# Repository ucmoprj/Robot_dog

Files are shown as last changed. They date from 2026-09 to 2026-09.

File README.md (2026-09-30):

# MG90S Dog R1

A mechanical design for review that rebuilds the **4 legs × 3 joints** layout of Rhoban's `dog_mujoco` and `dog_urdf` around MG90S servos. The joint names and kinematic structure of both originals were checked, and new geometry, masses, inertias and joint limits were made for the MG90S. It is not a simple scaled-down copy of the original CAD.

Generated output is in `out/mg90s_dog`. This design is separate from the `leg_*.step` files and `sim` model of the earlier ESP32 quadruped.

## Design constraints

- 12 × MG90S: 4 body-side roll, 4 hip pitch, 4 knee pitch.
- Body plate 116 × 66 mm, shoulder vertical offset 37 mm, lateral offset 16 mm.
- Upper leg 44 mm between axes, 38 mm from the lower-leg axis to the foot center, foot radius 5 mm.
- Default knee angle 42°. The hip angle is computed from the two link lengths so the foot sits under the hip.
- Roll is limited to 18° outward and 6° inward. Tilting too far inward makes the leg hit the opposite knee servo, so left and right legs get limits of opposite sign.
- Estimated mass follows the generated `design_summary.json` and `bom.csv`: a conditional estimate of about 0.31 kg.
- Includes battery 30 g, PCA9685 12 g, controller board 10 g, IMU 2 g, wiring/regulator 10 g, fasteners 10 g. Extra payload 0 g.
- The effective print density of 900 kg/m³ is an assumption. Replace it with the slicer's filament usage and the measured weight.

From the manufacturer's MG90S spec: mass 13.4 g, overall size 22.8 × 12.2 × 28.5 mm, stall torque about 0.1765 N·m at 4.8 V, 60°/0.10 s. **The 0.06 N·m design limit is a conservative assumption, not a continuous torque guaranteed by the manufacturer.** Mounting ears, output shaft position and horn hole sizes are adjustable values that need checking against the real part.

Source: https://towerpro.com.tw/product/mg90s-3/

## Opening in Onshape

1. To check the shape, import `onshape/mg90s_dog_assembly.step`. It is saved in the standing pose.
2. To build a movable Assembly, **`onshape/mg90s_dog_zero.step`** is easier. The body origin is at (0,0,0) and every joint is at its geometric reference angle of 0°. This pose is the assembly reference, not a walking pose.
3. The STEP hierarchy has 13 rigid groups such as `body`, `fl_shoulder`, `fl_thigh`, `fl_shank`. Fix the parts of each group so they move together.
4. Create 12 Revolute Mates following the origins and axes in `onshape/onshape_mates.csv`. Align each Mate connector's Z axis with the rotation axis in the table. Name them `dof_fl_1` through `dof_br_3`.
5. Apply the rotation limits and standing angles from the CSV. `*_1` is roll, `*_2` hip pitch, `*_3` knee pitch.
6. The IMU frame is at (0,0,26) mm in the body frame, X forward, Y left, Z up. It can be added as `frame_imu`.

STEP carries shape, names and placement. **It does not create Onshape Mates or the original sketch/feature history.** Depending on how the hierarchy imports, group the parts of each rigid body with Group or Fastened Mates. The CAD model was generated locally and did not modify the user's Onshape documents directly.

If you build mates directly on the standing STEP, the current pose may become 0°. The CSV's absolute angles would then be wrong, so the zero STEP is recommended. When exporting again with `onshape-to-robot`, compare the joint axes, zeros and masses with the current MJCF. Do not let Onshape estimate the MG90S internal mass from a generic material density; apply the rigid-body masses and inertias from `design_summary.json` separately.

Source: https://onshape-to-robot.readthedocs.io/en/latest/design.html

## Printing and assembly

`onshape/parts` holds a STEP per printed part and `onshape/print_stl` holds STLs in mm. Part files keep their rigid-body coordinates, so place a flat face on the bed in the slicer. Some parts are mirrored for left/right and front/back mounting; keep the file names.

First check the servo case clearance, ear hole spacing and pilot holes with `servo_fit_coupon.step` or the STL of the same name. Use the horns that ship with the MG90S; the round horn in the model is a stand-in for mass and space. Do not assume a printed spline will mate with the servo shaft. If the real horn shape and the 6 mm-radius screw holes differ, change `horn_screw_radius` and related values.

Screw the servo ears to the frame and the horn to the rotating bracket. There is an access hole for the horn's center screw. After checking plate/frame and screw fit, assemble one leg and check its motion. The current design relies on the MG90S's own output shaft support; it is not a double-supported design with external bearings. Drop/impact durability and horn/pilot-hole pull-out strength need testing on the real part.

Electronics are held with slots and straps instead of a specific seller's hole pattern. The green parts are space reservations: PCA9685 62×25×5 mm, controller board 50×25×7 mm, IMU 20×16×3 mm. Also check real terminal and cable bend space. The IMU bridge is a draft fixed to the support in the center channel with adhesive or tape; a screw pattern for a specific module is not decided.

## Load and height

`load_screen` in `validation_report.json` computes the cases of weight shared equally by all four feet and by two diagonal feet. It uses each joint's Jacobian with masses and inertias summed from the CAD, multiplies the required torque by 1.5 and compares it with 0.06 N·m. The two-foot case is a load-sharing condition during walking, not a claim that the robot is statically stable on two feet.

Height and torque are recorded for knee angles of 25°, 42°, 60° and 75°. **Bending the legs more to lower the body can increase knee torque.** If you need a lower body, calculate shortening `upper_leg`/`lower_leg` and changing the bend angle as separate options. Shorter legs require re-checking servo/horn/frame interference.

The report's mass limit is an approximation that scales the load at the same pose; it is not a guaranteed payload. If the battery or part weights change, edit `parameters.json`, regenerate and re-validate. Stall torque, heat, gear backlash, voltage drop and impact contact forces are not validated by this load calculation alone.

## Simulation

From the project root:

```powershell
python design/mg90s_dog/build.py
python design/mg90s_dog/validate.py
python design/mg90s_dog/check_cad.py
python design/mg90s_dog/run.py --seconds 10
python design/mg90s_dog/run.py --viewer
```

- MuJoCo: `dog_mujoco/scene.xml`. Internal units m·kg·s, 1 ms step.
- URDF for Isaac Sim and similar: `dog_urdf/robot.urdf`. Keep it together with the `assets` folder. Import as a floating base and set the articulation root to body. It has not been run in Isaac Sim.
- URDF effort/velocity values alone do not reproduce the real actuator. In Isaac Sim, start with a position drive, max force 0.06 N·m, stiffness 1.8 N·m/rad and damping 0.035 N·m·s/rad, and apply the 50 Hz command rate and velocity limit in the controller. Check import options and drive units for your Isaac Sim version.

MuJoCo's direct position actuator only has a static torque limit and PD. Using `ServoBridge` in `control.py` adds a 50 Hz command rate, one-cycle command delay and a 4 rad/s command rate limit. This rate limit does not guarantee real shaft speed or torque-speed behavior. Initial PD, friction and joint armature are also assumptions until identified on hardware.

Tested package versions are recorded in `requirements-tested.txt`.

## Sim-to-real / real-to-sim

MG90S servos and a PCA9685 give no joint angle feedback. The default policy observation has 30 values: 3 gyro, 3 accelerometer, and 24 for the current and previous commands. Exact joint angles, joint velocities, foot contacts, world position and a perfect quaternion are not in the policy observation. The `ground_truth_orientation` sensor is for evaluation in simulation.

Measure and apply the real angle zeros, rotation signs, PWM pulse range and frequency, latency, speed, sag under load, and IMU bias and axis orientation. The proposed PCA9685 channels are FL 0/1/2, FR 3/4/5, BL 6/7/8, BR 9/10/11, which differ from the earlier ESP32 robot. Fill the nulls in `hardware_calibration.template.json` with measured values before use (see `hardware/calibrate.py` and `docs/servo_bench.html`). The model itself does not send I2C commands.

Still to do before transfer to hardware: identify mass, friction, torque, latency, IMU noise and zero error, and randomize them during training. A standing success in the validation files does not mean walking or sim-to-real transfer will succeed.

## Sources and limits

- Original: https://github.com/Rhoban/onshape-to-robot-examples — `source_audit.json` records the commit, Onshape URL, and comparison of original masses and joints. The original MIT license is kept in `LICENSE.Rhoban`.
- MuJoCo: https://mujoco.readthedocs.io/en/stable/XMLreference.html
- Isaac Sim URDF: https://docs.isaacsim.omniverse.nvidia.com/latest/importer_exporter/import_urdf.html

The current result is **a runnable simulation and CAD design R1 that can be reviewed in Onshape**. It is not a production-ready design validated for real MG90S fit, hardware mounting, heat, durability or print-orientation strength.

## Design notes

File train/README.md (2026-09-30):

# Training Pipeline — Command Reference

Commands to set up, train, monitor, and test the MG90S quadruped RL policies.
Run everything from the project root (`Robot_dog/`) unless noted otherwise.

## Setup

```bash
cd /home/UCMO/tkang/Robot_dog
source .venv/bin/activate
```

Verify the environment (mujoco, mujoco_warp, torch+CUDA, rsl_rl):

```bash
python -c "import mujoco, mujoco_warp, torch, rsl_rl; print('OK')"
python -c "import torch; print(torch.cuda.is_available(), torch.cuda.get_device_name(0))"
```

---

## 1. View the raw robot model (no policy, no training)

Just the physical model reacting to its position-actuator defaults (`ctrl=0`):

```bash
python -m mujoco.viewer --mjcf=dog_mujoco/scene.xml
```

Mouse drag = rotate camera, right-drag = pan, scroll = zoom, `Ctrl`+drag on the
robot = push it, `Space` = pause. The `Control` panel lets you move each joint
by hand.

---

## 2. View an environment under a zero/random policy (pre-training sanity check)

Uses `env.py`'s observation/reward/termination logic, but with a placeholder
policy (no neural network yet) — good for checking a task config before
spending time training it.

```bash
python train/view_task.py --task train/tasks/stand.yaml --policy zero
python train/view_task.py --task train/tasks/stand.yaml --policy random
```

---

## 3. Train (GPU-parallel PPO via rsl_rl)

Each command launches training in the foreground; add `nohup ... &` (or run it
in its own terminal) to keep it running in the background.

**Stand (balance) task:**
```bash
python train/train.py --task train/tasks/stand.yaml --num_envs 2048 --iterations 3000 --save_interval 25 --run_name live_demo
```

**Walk task (basic — body velocity only, no gait shaping):**
```bash
python train/train.py --task train/tasks/walk_forward.yaml --num_envs 2048 --iterations 3000 --save_interval 25 --run_name walk_demo
```

**Walk task (gait version — adds foot-contact-based `feet_air_time` /
`gait_symmetry` rewards, encourages actually lifting the legs instead of
shuffling):**
```bash
python train/train_gait.py --task train/tasks/walk_forward_gait.yaml --num_envs 2048 --iterations 3000 --save_interval 25 --run_name walk_gait_demo
```

Common flags: `--num_envs` (parallel environments), `--iterations`, `--device`
(default `cuda:0`), `--seed`, `--run_name` (log folder name under
`train/logs/`).

Checkpoints and TensorBoard logs are written to `train/logs/<run_name>/`.

---

## 4. Monitor training

**TensorBoard** (auto-detects every run under `train/logs/`, compare multiple
runs with the "Runs" checkboxes on the left):
```bash
tensorboard --logdir train/logs --bind_all
```

**Custom dashboard** (per-graph collapsible English explanations of what each
metric means and which direction is "good" — a companion to TensorBoard, not
a replacement):
```bash
python train/dashboard_server.py --logdir train/logs/live_demo --port 6007
python train/dashboard_server.py --logdir train/logs/walk_demo --port 6008
python train/dashboard_server_gait.py --logdir train/logs/walk_gait_demo --port 6009
```
Open `http://<host>:<port>/` in a browser; auto-refreshes every 3s.

Find the latest checkpoint for a run:
```bash
ls -t train/logs/<run_name>/*.pt | head -1
```

---

## 5. Test / play a trained checkpoint in the MuJoCo viewer

`--task` must match the task the checkpoint was actually trained on (its
reward/termination config affects resets during playback). Works for
checkpoints from **any** of the three training commands above — the
observation/action shapes are identical (only the reward differs), so the
same `play.py` covers all of them, including the gait version.

```bash
python train/play.py --task train/tasks/stand.yaml         --checkpoint train/logs/live_demo/model_<N>.pt
python train/play.py --task train/tasks/walk_forward.yaml       --checkpoint train/logs/walk_demo/model_<N>.pt
python train/play.py --task train/tasks/walk_forward_gait.yaml  --checkpoint train/logs/walk_gait_demo/model_<N>.pt
```

Rendering runs on CPU (`mujoco`), independent from the GPU training process —
training keeps running in the background while you watch a checkpoint.

---

## 6. Useful one-offs

Check GPU utilization while training runs:
```bash
nvidia-smi --query-gpu=utilization.gpu,memory.used,memory.total --format=csv
```

Check a training run's current iteration / latest reward from its log file:
```bash
grep "Learning iteration" train/logs_<run_name>_stdout.log | tail -1
grep "Mean reward:" train/logs_<run_name>_stdout.log | tail -1
```

Stop a background training run (checkpoints already saved are kept):
```bash
pkill -f "train/train.py --task train/tasks/<name>.yaml"       # stand / walk_forward
pkill -f "train/train_gait.py --task train/tasks/<name>.yaml"  # walk_forward_gait
```

---

## File map

| File | Role |
|---|---|
| `reward_terms.py` | Reusable reward functions + `SimState` container (base) |
| `reward_terms_gait.py` | Extends the above with foot-contact-based gait rewards |
| `env.py` / `env_gait.py` | Single-env CPU wrapper (dev/visualization/`play.py`) |
| `vec_env.py` / `vec_env_gait.py` | GPU-parallel batched env (`mujoco_warp`) for training |
| `ppo_config.py` | PPO/network hyperparameters, shared by all training scripts |
| `train.py` / `train_gait.py` | Training entry points |
| `play.py` | Loads a checkpoint, runs it live in the mujoco viewer |
| `view_task.py` | Views a task under a zero/random (untrained) policy |
| `dashboard_server.py` / `dashboard_server_gait.py` | Local monitoring dashboard |
| `tasks/*.yaml` | Reward weights and task settings — the only thing that should change between experiments |

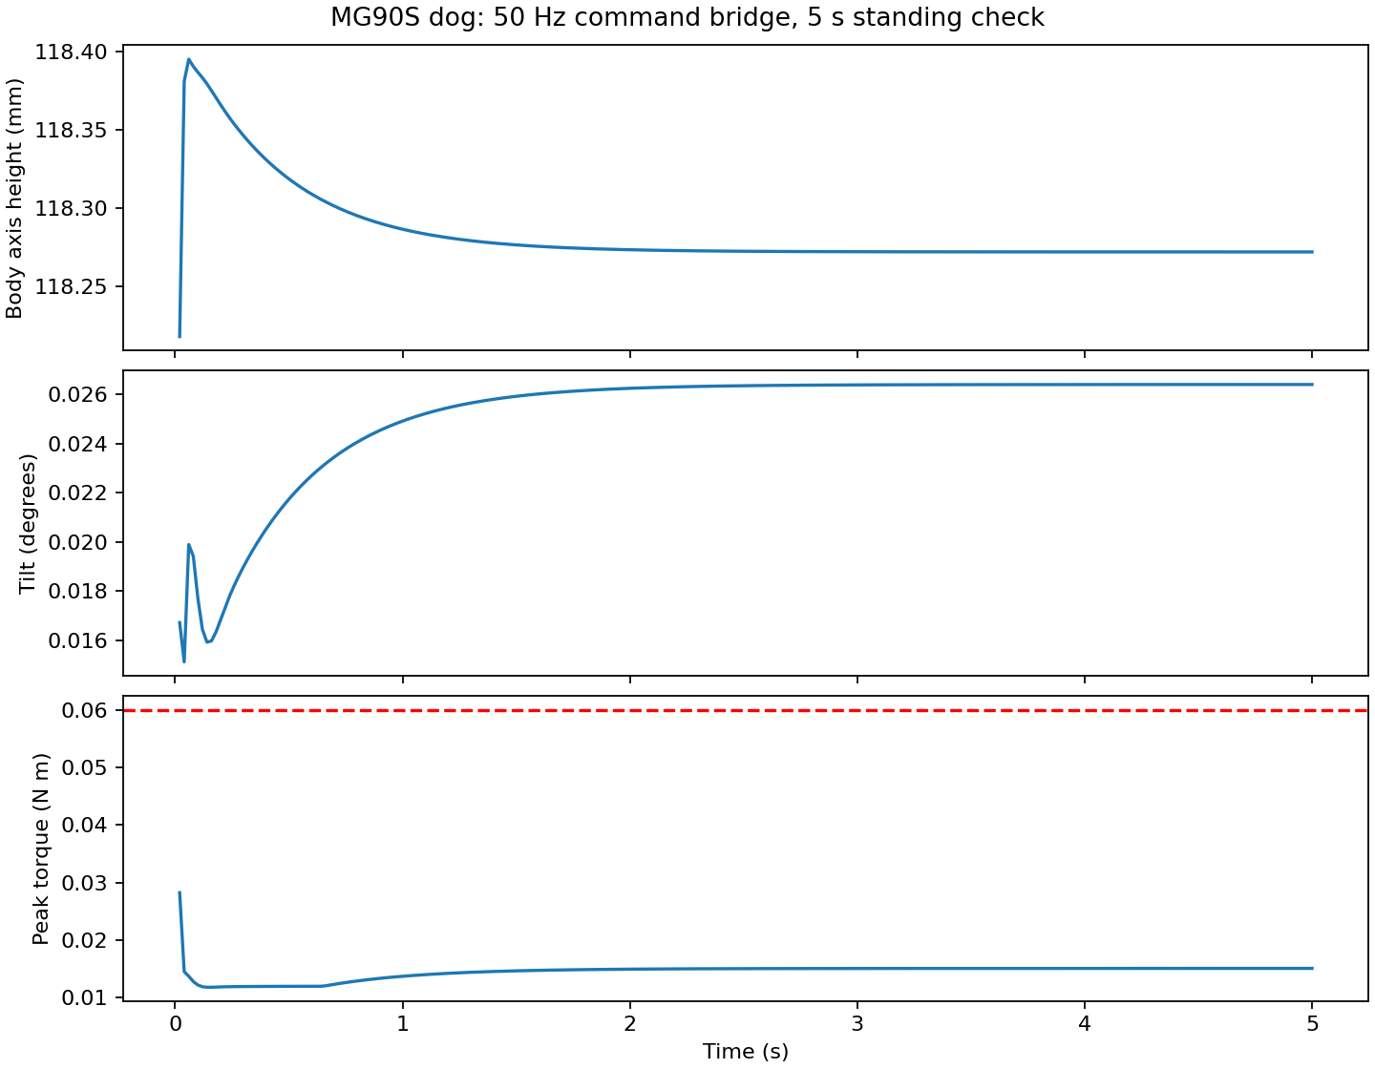
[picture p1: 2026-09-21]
standing_check.png

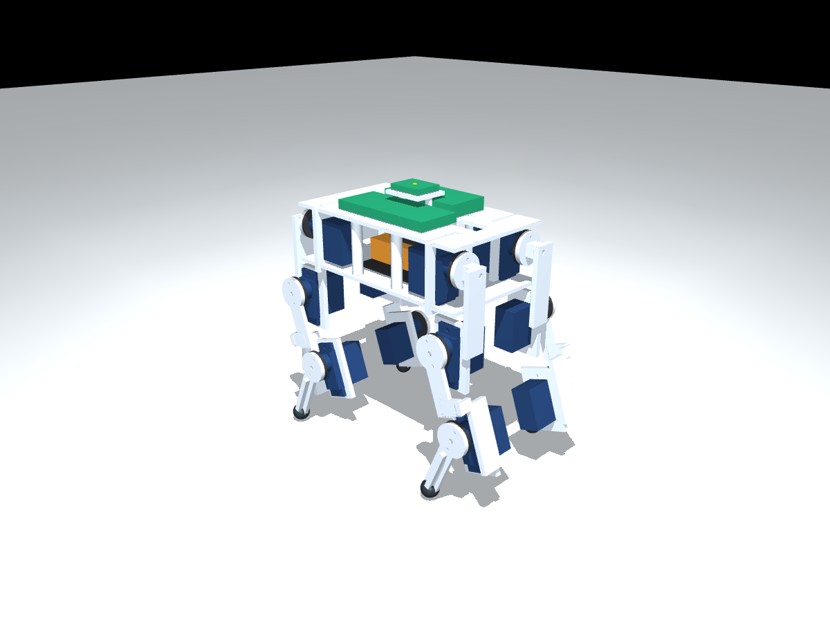
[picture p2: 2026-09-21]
mg90s_dog_preview.png

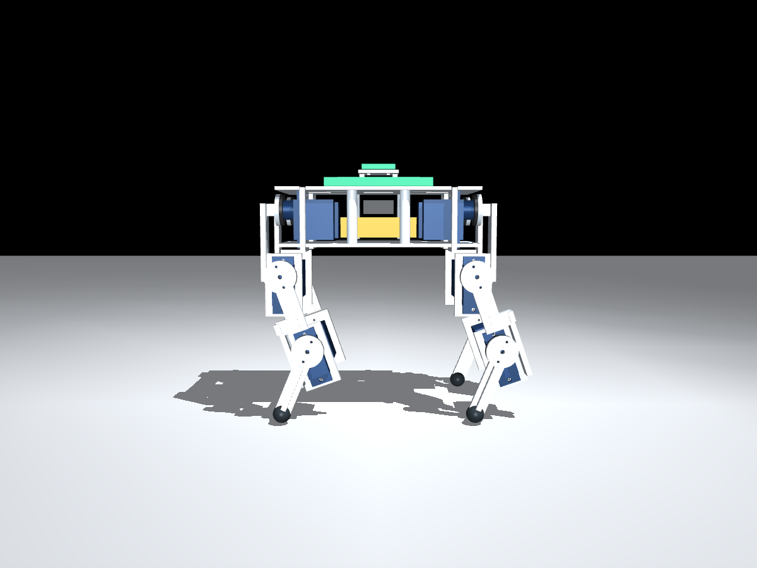
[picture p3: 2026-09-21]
view_side.png

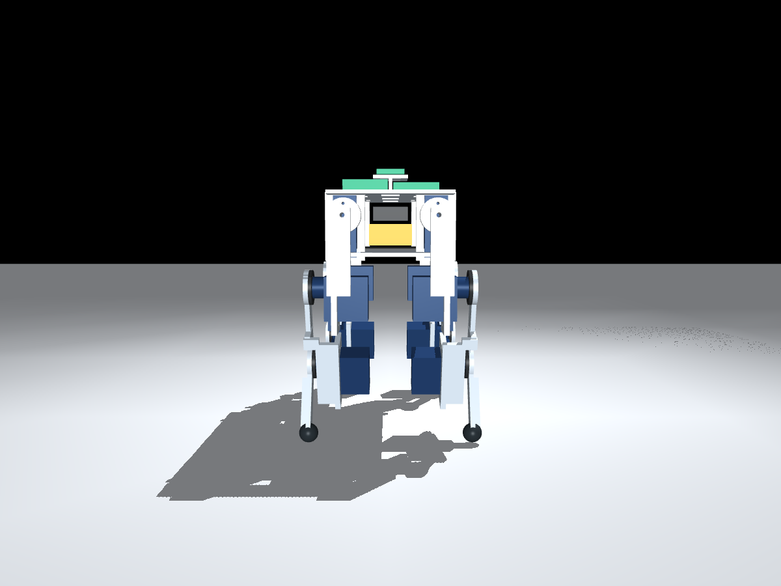
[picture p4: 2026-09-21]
view_front.png

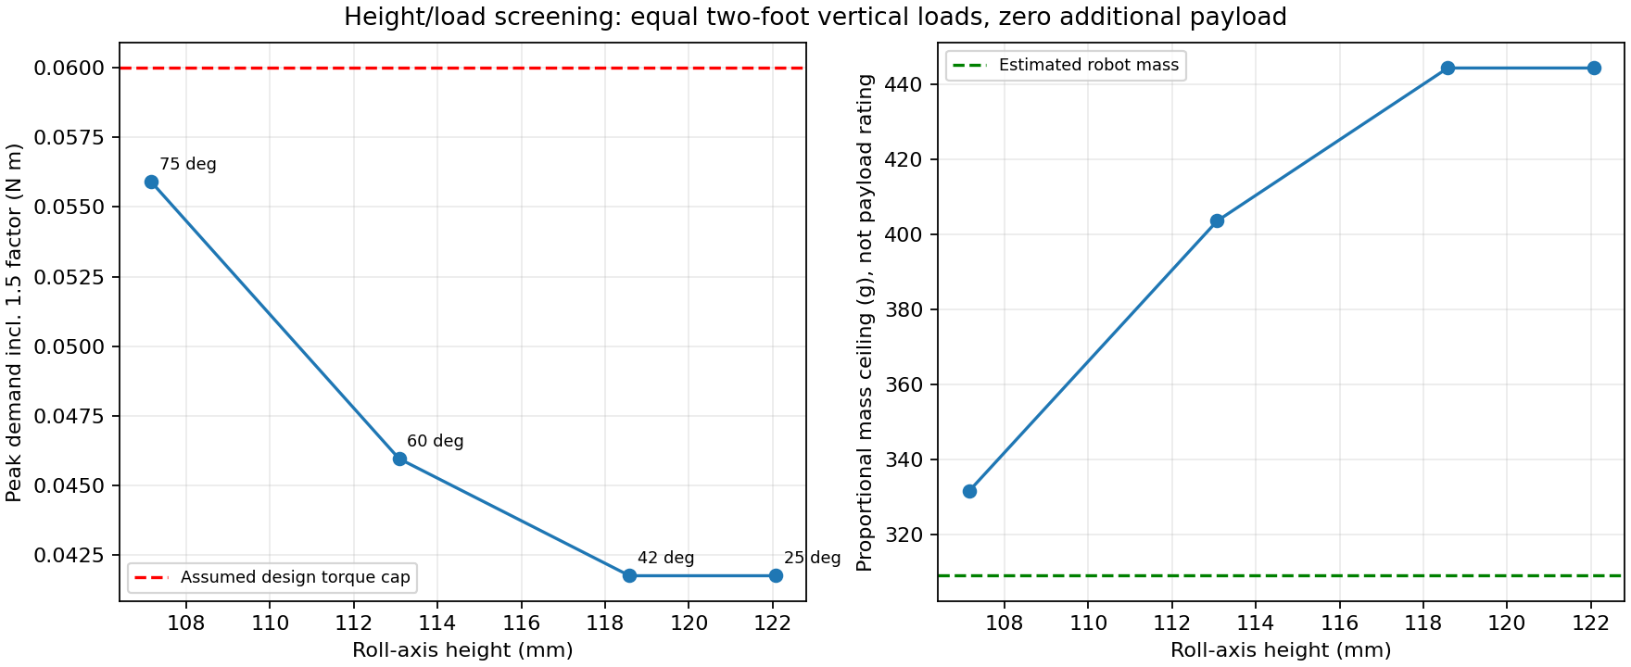
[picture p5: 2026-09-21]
height_load_screen.png

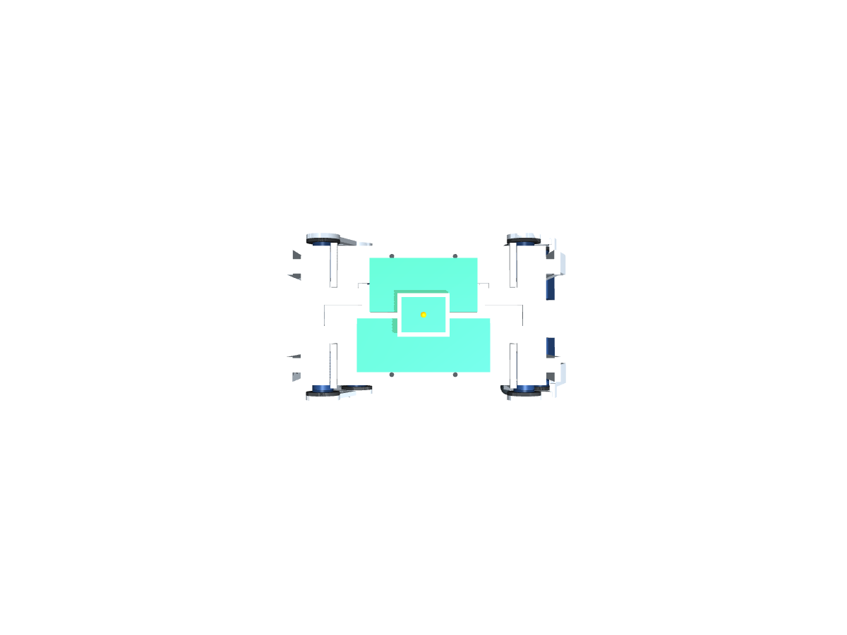
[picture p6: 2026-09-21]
view_top.png

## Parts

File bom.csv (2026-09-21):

component | rigid_link | kind | printable | mass_g | solid_count
fl_roll_MG90S | body | servo | False | 13.4 | 1
fr_roll_MG90S | body | servo | False | 13.4 | 1
bl_roll_MG90S | body | servo | False | 13.4 | 1
br_roll_MG90S | body | servo | False | 13.4 | 1
body_base | body | print | True | 20.328 | 1
electronics_deck | body | print | True | 12.052 | 1
imu_bridge | body | print | True | 0.875 | 1
battery_envelope | body | battery | False | 30.0 | 1
PCA9685_envelope | body | board | False | 12.0 | 1
controller_envelope | body | board | False | 10.0 | 1
IMU_envelope | body | board | False | 2.0 | 1
wiring_regulator_allowance | body | horn | False | 10.0 | 1
fastener_mass_allowance | body | horn | False | 10.0 | 1
fl_shoulder_bracket | fl_shoulder | print | True | 3.356 | 1
fl_roll_horn | fl_shoulder | horn | False | 0.4 | 1
fl_hip_MG90S | fl_shoulder | servo | False | 13.4 | 1
fl_thigh_bracket | fl_thigh | print | True | 3.628 | 1
fl_hip_horn | fl_thigh | horn | False | 0.4 | 1
fl_knee_MG90S | fl_thigh | servo | False | 13.4 | 1
fl_lower_leg | fl_shank | print | True | 1.487 | 1
fl_knee_horn | fl_shank | horn | False | 0.4 | 1
fl_foot_pad | fl_shank | foot | False | 0.6 | 1
fr_shoulder_bracket | fr_shoulder | print | True | 3.356 | 1
fr_roll_horn | fr_shoulder | horn | False | 0.4 | 1
fr_hip_MG90S | fr_shoulder | servo | False | 13.4 | 1
fr_thigh_bracket | fr_thigh | print | True | 3.628 | 1
fr_hip_horn | fr_thigh | horn | False | 0.4 | 1
fr_knee_MG90S | fr_thigh | servo | False | 13.4 | 1
fr_lower_leg | fr_shank | print | True | 1.487 | 1
fr_knee_horn | fr_shank | horn | False | 0.4 | 1
fr_foot_pad | fr_shank | foot | False | 0.6 | 1
bl_shoulder_bracket | bl_shoulder | print | True | 3.356 | 1
bl_roll_horn | bl_shoulder | horn | False | 0.4 | 1
bl_hip_MG90S | bl_shoulder | servo | False | 13.4 | 1
bl_thigh_bracket | bl_thigh | print | True | 3.628 | 1
bl_hip_horn | bl_thigh | horn | False | 0.4 | 1
bl_knee_MG90S | bl_thigh | servo | False | 13.4 | 1
bl_lower_leg | bl_shank | print | True | 1.487 | 1
bl_knee_horn | bl_shank | horn | False | 0.4 | 1
bl_foot_pad | bl_shank | foot | False | 0.6 | 1
br_shoulder_bracket | br_shoulder | print | True | 3.356 | 1
br_roll_horn | br_shoulder | horn | False | 0.4 | 1
br_hip_MG90S | br_shoulder | servo | False | 13.4 | 1
br_thigh_bracket | br_thigh | print | True | 3.628 | 1
br_hip_horn | br_thigh | horn | False | 0.4 | 1
br_knee_MG90S | br_thigh | servo | False | 13.4 | 1
br_lower_leg | br_shank | print | True | 1.487 | 1
br_knee_horn | br_shank | horn | False | 0.4 | 1
br_foot_pad | br_shank | foot | False | 0.6 | 1

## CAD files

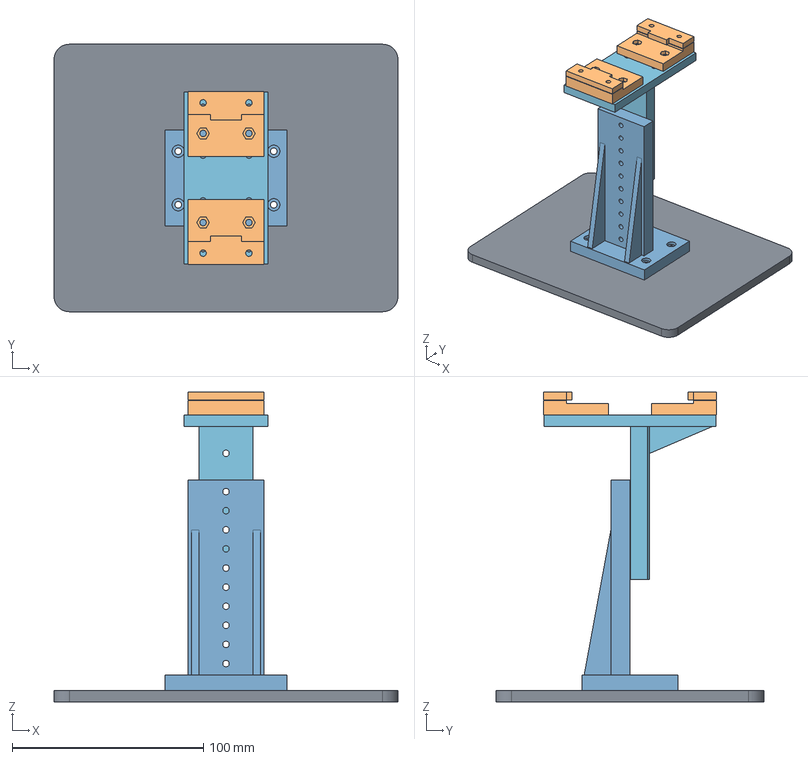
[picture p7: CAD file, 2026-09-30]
calibration_stand/output/stand_assembly.step
180.0 x 140.0 x 162.0 mm
base
mast
carriage
jaw_left
cap_left
jaw_right
cap_right

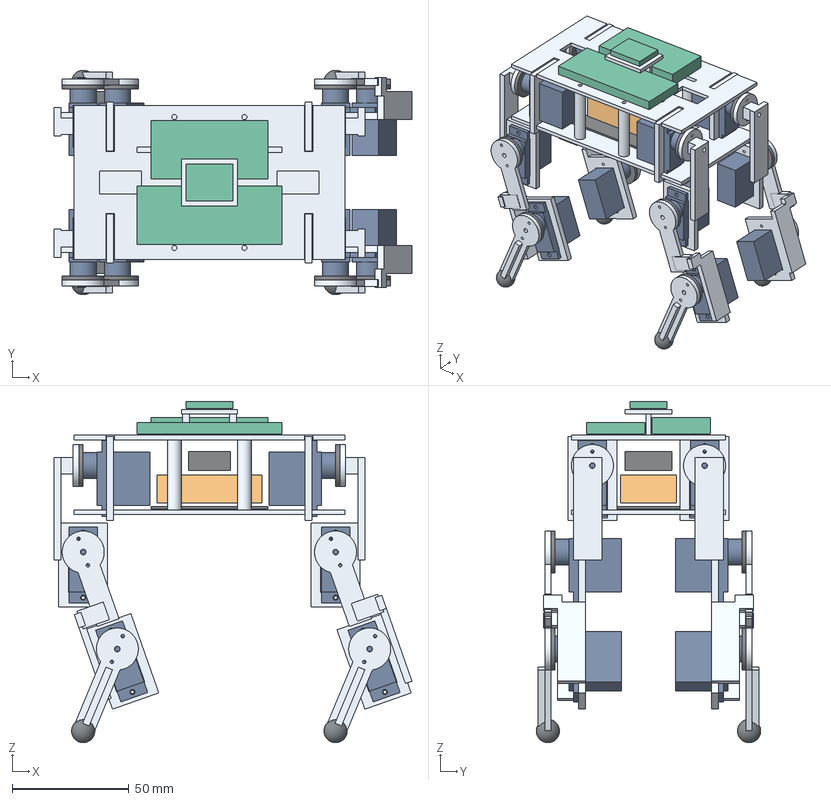
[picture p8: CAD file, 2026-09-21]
onshape/mg90s_dog_assembly.step
153.2 x 96.1 x 146.1 mm
fl_roll_MG90S
fr_roll_MG90S
bl_roll_MG90S
br_roll_MG90S
body_base
electronics_deck
imu_bridge
battery_envelope
PCA9685_envelope
controller_envelope
IMU_envelope
wiring_regulator_allowance
fastener_mass_allowance
fl_shoulder_bracket
fl_roll_horn
fl_hip_MG90S
fl_thigh_bracket
fl_hip_horn
fl_knee_MG90S
fl_lower_leg
fl_knee_horn
fl_foot_pad
fr_shoulder_bracket
fr_roll_horn
fr_hip_MG90S
fr_thigh_bracket
fr_hip_horn
fr_knee_MG90S
fr_lower_leg
fr_knee_horn
fr_foot_pad
bl_shoulder_bracket
bl_roll_horn
bl_hip_MG90S
bl_thigh_bracket
bl_hip_horn
bl_knee_MG90S
bl_lower_leg
bl_knee_horn
bl_foot_pad
br_shoulder_bracket
br_roll_horn
br_hip_MG90S
br_thigh_bracket
br_hip_horn
br_knee_MG90S
br_lower_leg
br_knee_horn
br_foot_pad

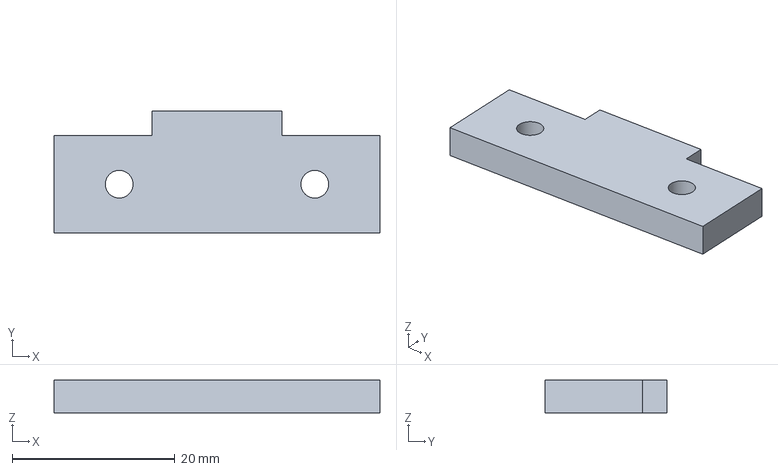
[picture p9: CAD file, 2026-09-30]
calibration_stand/output/parts_step/cap_right.step
40.0 x 15.0 x 4.00 mm

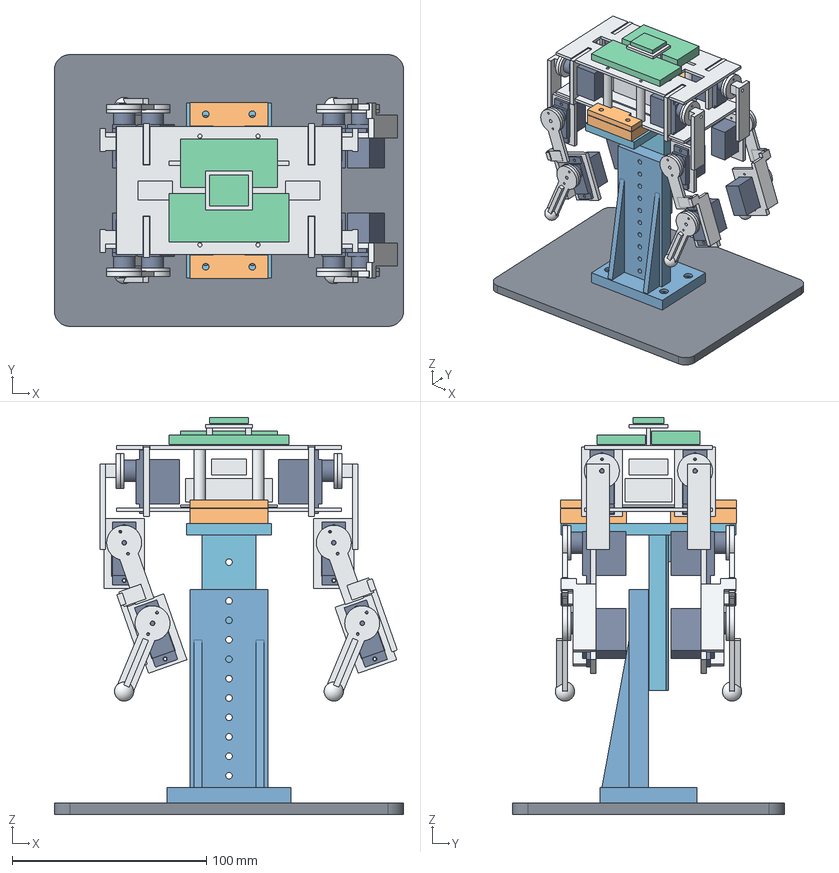
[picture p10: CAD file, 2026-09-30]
calibration_stand/output/robot_on_stand.step
180.0 x 140.0 x 204.5 mm
base
mast
carriage
jaw_left
cap_left
jaw_right
cap_right
fl_roll_MG90S
fr_roll_MG90S
bl_roll_MG90S
br_roll_MG90S
body_base
electronics_deck
imu_bridge
battery_envelope
PCA9685_envelope
controller_envelope
IMU_envelope
wiring_regulator_allowance
fastener_mass_allowance
fl_shoulder_bracket
fl_roll_horn
fl_hip_MG90S
fl_thigh_bracket
fl_hip_horn
fl_knee_MG90S
fl_lower_leg
fl_knee_horn
fl_foot_pad
fr_shoulder_bracket
fr_roll_horn
fr_hip_MG90S
fr_thigh_bracket
fr_hip_horn
fr_knee_MG90S
fr_lower_leg
fr_knee_horn
fr_foot_pad
bl_shoulder_bracket
bl_roll_horn
bl_hip_MG90S
bl_thigh_bracket
bl_hip_horn
bl_knee_MG90S
bl_lower_leg
bl_knee_horn
bl_foot_pad
br_shoulder_bracket
br_roll_horn
br_hip_MG90S
br_thigh_bracket
br_hip_horn
br_knee_MG90S
br_lower_leg
br_knee_horn
br_foot_pad

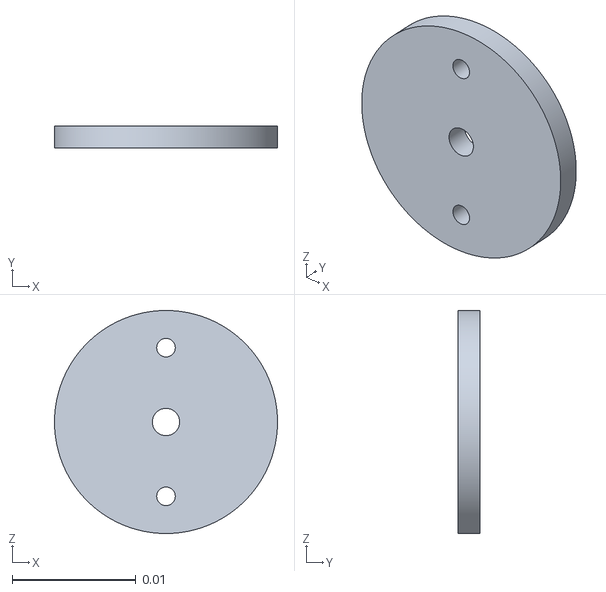
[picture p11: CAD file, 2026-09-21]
dog_mujoco/assets/fl_knee_horn.stl
0.018 x 0.0018 x 0.018

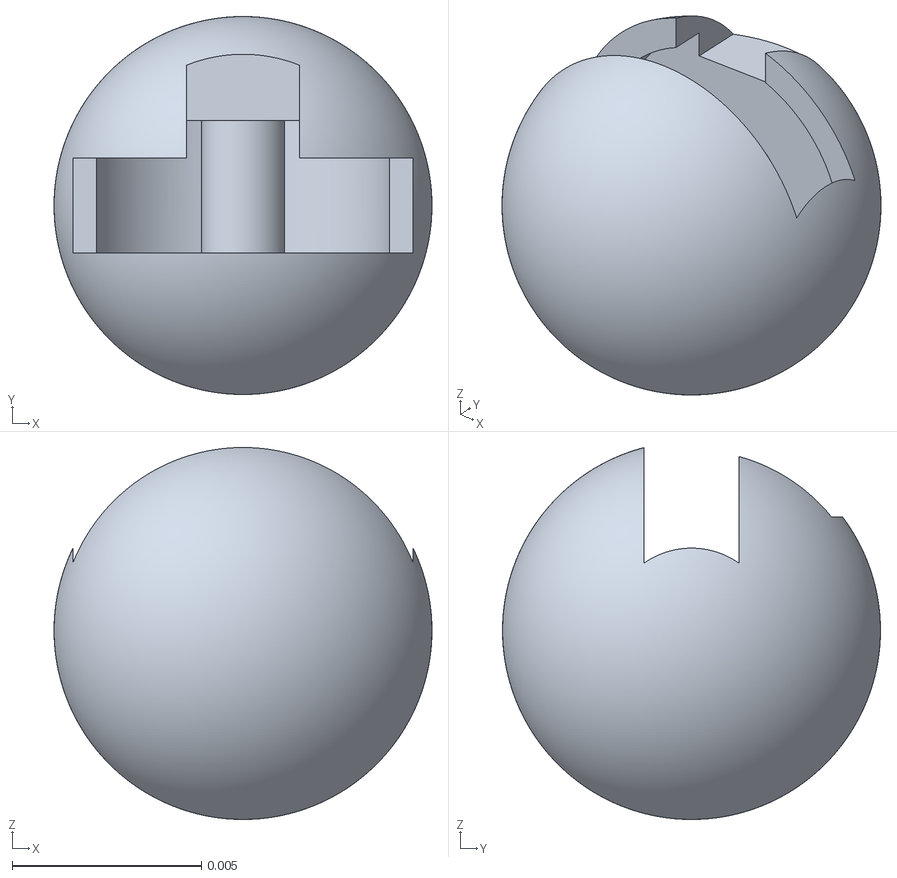
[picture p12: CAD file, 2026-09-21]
dog_urdf/assets/fl_foot_pad.stl
0.01 x 0.01 x 0.00984

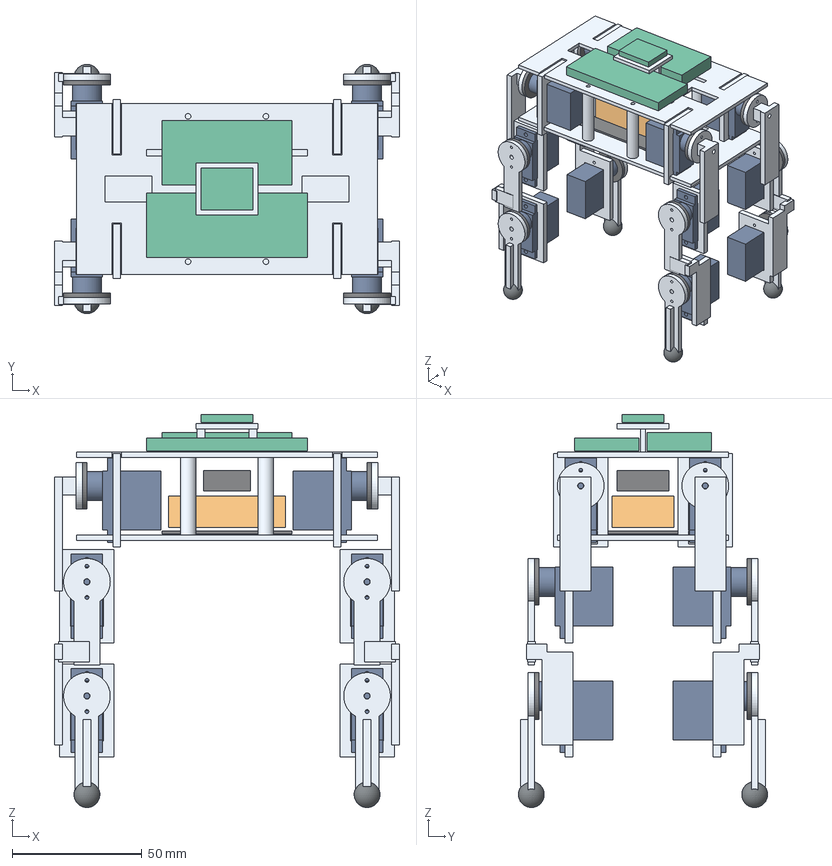
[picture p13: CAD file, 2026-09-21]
onshape/mg90s_dog_zero.step
133.0 x 96.1 x 151.5 mm
fl_roll_MG90S
fr_roll_MG90S
bl_roll_MG90S
br_roll_MG90S
body_base
electronics_deck
imu_bridge
battery_envelope
PCA9685_envelope
controller_envelope
IMU_envelope
wiring_regulator_allowance
fastener_mass_allowance
fl_shoulder_bracket
fl_roll_horn
fl_hip_MG90S
fl_thigh_bracket
fl_hip_horn
fl_knee_MG90S
fl_lower_leg
fl_knee_horn
fl_foot_pad
fr_shoulder_bracket
fr_roll_horn
fr_hip_MG90S
fr_thigh_bracket
fr_hip_horn
fr_knee_MG90S
fr_lower_leg
fr_knee_horn
fr_foot_pad
bl_shoulder_bracket
bl_roll_horn
bl_hip_MG90S
bl_thigh_bracket
bl_hip_horn
bl_knee_MG90S
bl_lower_leg
bl_knee_horn
bl_foot_pad
br_shoulder_bracket
br_roll_horn
br_hip_MG90S
br_thigh_bracket
br_hip_horn
br_knee_MG90S
br_lower_leg
br_knee_horn
br_foot_pad

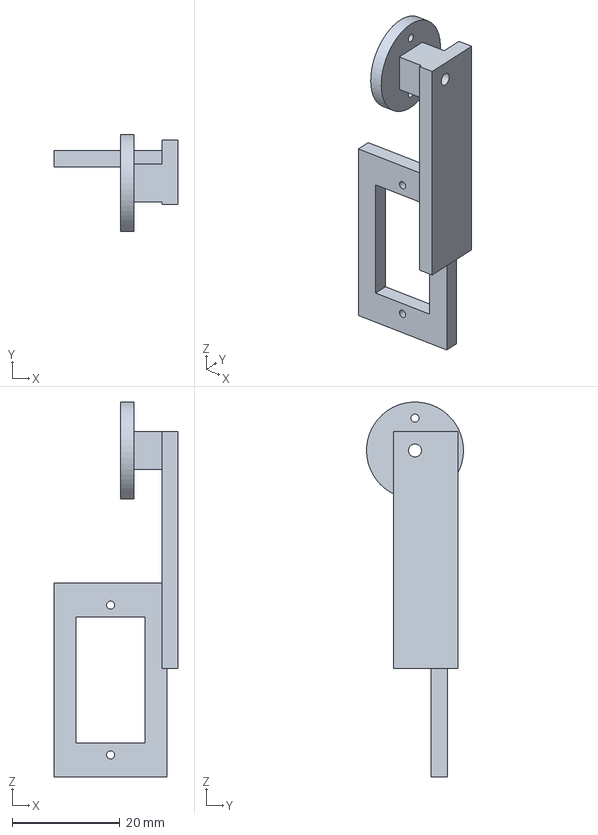
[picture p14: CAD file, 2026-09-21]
onshape/parts/fl_shoulder_bracket.step
23.0 x 18.0 x 69.6 mm

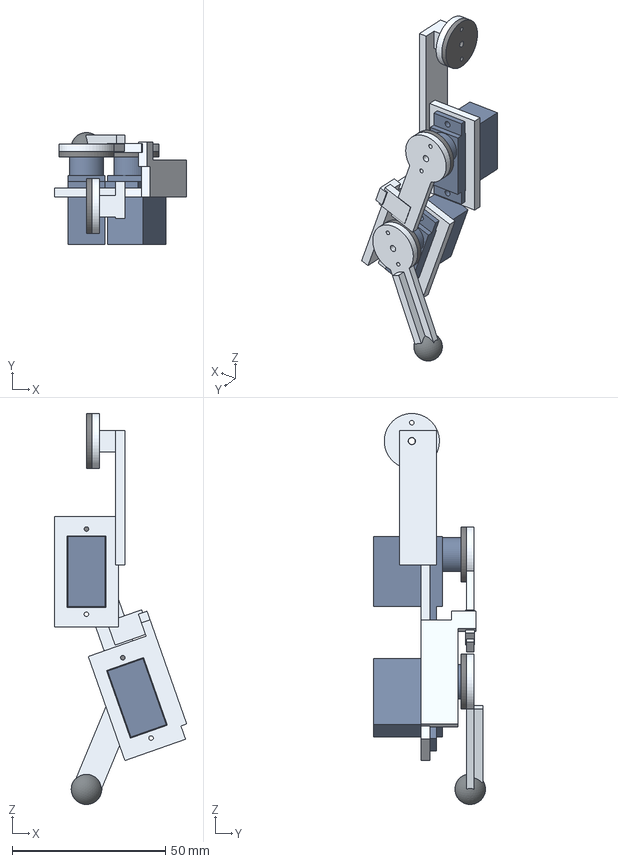
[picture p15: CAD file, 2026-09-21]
onshape/front_left_leg.step
43.2 x 36.5 x 127.6 mm
fl_shoulder_bracket
fl_roll_horn
fl_hip_MG90S
fl_thigh_bracket
fl_hip_horn
fl_knee_MG90S
fl_lower_leg
fl_knee_horn
fl_foot_pad

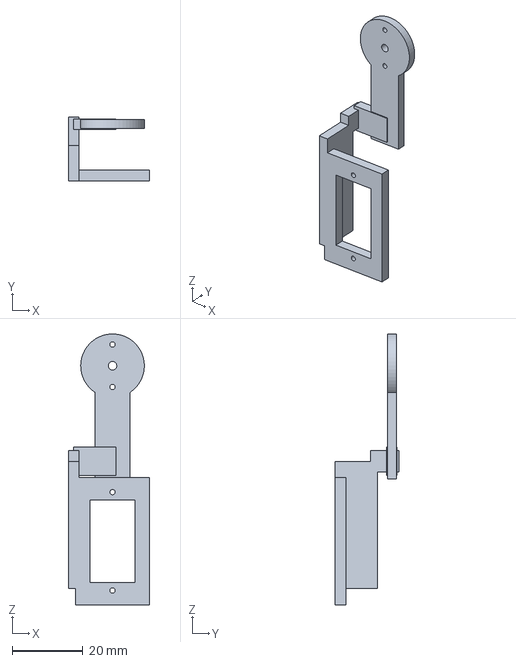
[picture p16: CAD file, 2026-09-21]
onshape/parts/bl_thigh_bracket.step
23.0 x 18.0 x 76.6 mm

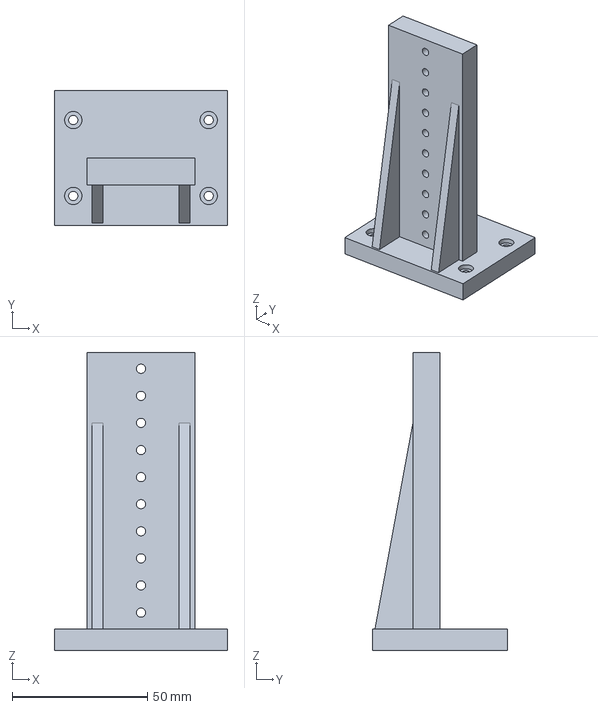
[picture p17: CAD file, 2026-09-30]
calibration_stand/output/parts_step/mast.step
64.0 x 50.0 x 110.0 mm

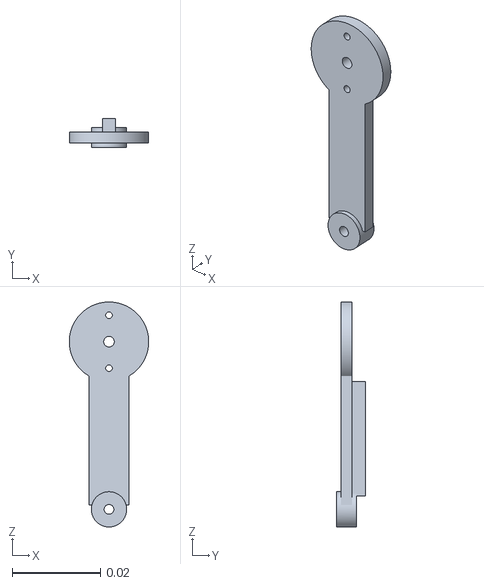
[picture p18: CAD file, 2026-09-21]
dog_urdf/assets/fl_lower_leg.stl
0.018 x 0.0065 x 0.051

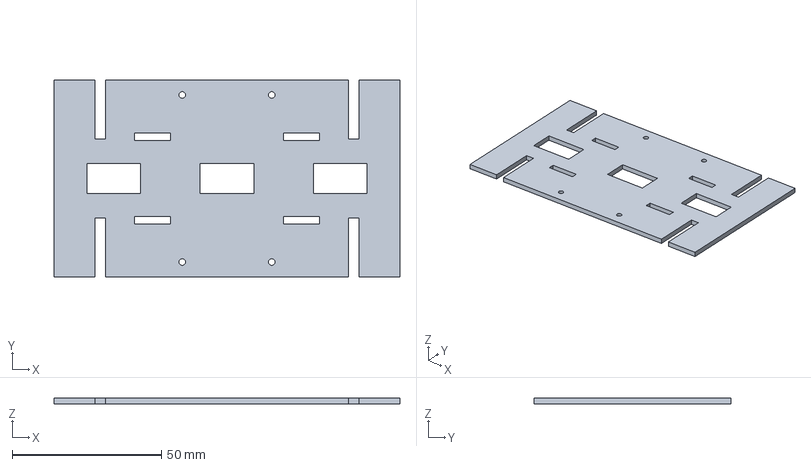
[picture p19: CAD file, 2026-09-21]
onshape/parts/electronics_deck.step
116.0 x 66.0 x 2.00 mm

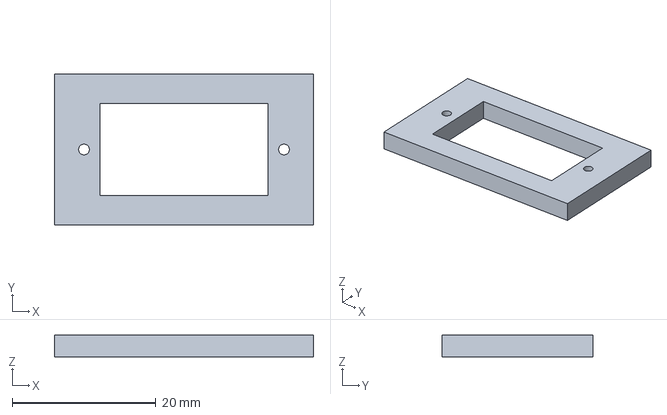
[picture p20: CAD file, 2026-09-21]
onshape/servo_fit_coupon.step
36.0 x 21.0 x 3.00 mm

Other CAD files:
calibration_stand/output/parts_step/cap_left.step
dog_mujoco/assets/bl_roll_horn.stl
dog_mujoco/assets/br_hip_horn.stl
calibration_stand/output/parts_step/base.step
calibration_stand/output/parts_step/carriage.step
calibration_stand/output/parts_step/fit_coupon.step
calibration_stand/output/parts_step/jaw_left.step
calibration_stand/output/parts_step/jaw_right.step
calibration_stand/output/print_stl/base.stl
calibration_stand/output/print_stl/cap_left.stl
calibration_stand/output/print_stl/cap_right.stl
calibration_stand/output/print_stl/carriage.stl
calibration_stand/output/print_stl/fit_coupon.stl
calibration_stand/output/print_stl/jaw_left.stl
calibration_stand/output/print_stl/jaw_right.stl
calibration_stand/output/print_stl/mast.stl
dog_mujoco/assets/IMU_envelope.stl
dog_mujoco/assets/PCA9685_envelope.stl
dog_mujoco/assets/battery_envelope.stl
dog_mujoco/assets/bl_foot_pad.stl
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

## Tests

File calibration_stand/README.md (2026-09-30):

# Small Quadruped Calibration Stand R1

A **design for review and test printing** for MG90S-DOG-R1. It is a center-support stand built around a P1S printer, PLA, and M3 screws and nuts. Other small robots of similar weight can use it by adjusting the support width or swapping only the supports. Real print stiffness, fastener holding force and interference with real cables have not been verified yet.

## Files

- `output/robot_on_stand.step`: the whole layout with the current robot on the stand. Open this in Onshape first.
- `output/stand_assembly.step`: assembly STEP of the stand only.
- `output/parts_step/`: one STEP per part, keeping assembly coordinates.
- `output/print_stl/`: STLs in mm, in print orientation. One file per part; the coupon is an optional test piece.
- `output/preview_robot.png`, `preview_stand.png`: previews rendered from the actual CAD geometry.
- `output/validation.json`: interference check and print size results.
- `build.py`, `parameters.json`: the editable, regenerable CadQuery source.

**This was not created directly as an Onshape document.** In a new document, use + → Import to bring in the STEP. Imported geometry has no original sketch/feature history or Mates. Add Mates or edit based on the part names and placement. To rebuild it with native features, use the dimension table below.

## Dimensions and adaptability

| Item | Value |
|---|---|
| Base plate | 180 × 140 × 6 mm, corner R8 |
| Fixed mast overall | 64 × 50 × 110 mm, mounted on the base plate |
| Mast vertical plate | 40 wide × 10 thick |
| Carriage vertical part | 28 wide × 10 thick × 80 long |
| Top platform | 44 × 90 × 6 mm |
| Body underside support height | 136 / 146 / **156** / 166 / 176 mm |
| Current body plate width | 66 mm, side clearance 0.3 mm each side |
| Body plate width range | 50–80 mm recommended; adjusted in the slots of the same parts |
| Front-back contact length of the supports | 40 mm, not adjustable |
| Cap inner contact tongue | 16 wide × 3 mm protrusion |
| Body base plate thickness the current cap targets | 2 mm |
| M3 clearance hole | Ø3.4 mm |
| Nut pocket | 5.7 mm across flats; check against real nuts and print tolerance |

The default `platform_height=150` is the top of the platform; the actual support surface is +6 mm. Set it from 130 to 170 mm in 10 mm steps. `body_width` can be set from 50 to 80 mm. After editing the source, regenerate with `python calibration_stand/build.py`.

"Adaptable" does not mean every robot's shape fits. The body needs an accessible 40 mm front-back support area in the middle and base plate edges on both sides. If the base plate is not 2 mm thick, or there are cables, a battery or other protrusions, modify the jaw/cap adapters. Front-back movement of the robot is held only by the cap's clamping friction. There is no separate stopper at the front or back.

The robot's BREP was inspected and the underside of the center lower plate at z=-21 mm is used as the support surface. The battery underside is at z=-16 mm, so the supports never touch the battery. The cap's center tongue avoids the body support posts near x=±15 mm.

## Parts and fasteners

There are **7** printed parts: base, mast, carriage, jaw_left/right, cap_left/right. The test piece fit_coupon is separate.

| Joint | Screw | Nut | Qty | Notes |
|---|---|---|---|---|
| Base plate ↔ mast | M3 × 12 mm | M3 standard hex | 4 sets | 2 mm counterbore on top of the mast feet, nut pocket under the base plate |
| Fixed mast ↔ carriage | M3 × 25 mm | M3 standard hex | 2 sets | uses two holes 20 mm apart; the rear nuts are exposed |
| Platform ↔ left/right supports | M3 × 12 mm | M3 standard hex | 4 sets | inserted from under the platform, nut pocket on top of the support |
| Support ↔ clamp cap | M3 × 10 mm | M3 standard hex | 4 sets | inserted from above the cap, deep nut pocket under the support |
| Total | 12 mm × 8 / 25 mm × 2 / 10 mm × 4 | 14 | 14 sets | screw length is under-head length |

Screw heads are assumed cylindrical/socket head fitting a Ø6.4 mm counterbore. The design is not for countersunk heads. Nuts are plain nuts, not inserts or heat-set nuts. The cap nut pockets are 4.6 mm deep; push the nut up against the pocket ceiling. Check hole depths and real screw/nut heights with the coupon and during assembly. Screws and nuts are not included in the STEP.

1. Use the coupon to test the M3 clearance hole, nut fit and the 2.3 mm gap.
2. Put the nuts under the base plate and fix the mast with four screws.
3. Hold the carriage against the front of the mast and fix it at the desired height with the two screws 20 mm apart. At the default height, the holes at z=70 and 90 mm from the base can be used. Take the robot off before adjusting.
4. Pre-insert the four support nuts and the four cap nuts. Loosely fasten the four screws under the platform. The two 4 mm ribs under the carriage were each moved 6 mm toward the center so they do not block the slots. The vertical plate edge that overlapped the bolt head at the inner end of the slots was also cut back by up to 1.8 mm. All four slots have Ø7 mm head/tool access over the full travel of the bolt center. The center gap between the ribs is 8 mm, and the original slot positions, the platform's head-bearing surface and the width range are unchanged.
5. Place the robot in the center, fit both supports to the body width, then tighten the screws under the platform.
6. Fasten the caps so their center tongue covers the body plate. There is 0.3 mm of space under the outer side of the cap, so it clamps the plate. Do not fully tighten the caps with no robot in place, or they will deform.
7. First, with power off, check joint motion, cables and screw access. This stand is for zeroing and unloaded joint tests. It is not for walking tests where the feet push against the ground.

## PLA print starting values

A 0.4 mm nozzle, 0.2 mm layers, 5 walls, 5 top/bottom layers and about 30% infill are suggested as **starting values for a test print**. They are not validated strength numbers. Use the filament maker's PLA profile.

- base: put the large flat face on the bed. Check the short bridges over the nut pockets in the slicer.
- mast/carriage: the supplied STLs lie on their side so vertical loads don't act only in the layer-separation direction. The protruding feet and platform need supports; check the slicer preview.
- jaw: the supplied STL is upside down. Check supports under the step faces and remove any support left inside the nut pockets.
- cap/coupon: put the large face down.

Every part is checked to fit within 220 mm in XY in its print orientation. The official nominal P1S build volume is 256 × 256 × 256 mm. Keep the slicer's real exclusion zones and brim margin.

## Scope of the checks

Use the latest results in `validation.json`. An OpenCascade solid intersection above 0.05 mm³ is recorded as interference. Checked: every part pair inside the stand, the robot's default pose, and 5 points across each joint's limit range (other joints at the standing pose). 61 poses in total.

`carriage_slot_fastener_access` checks, for each of the four slots of the carriage alone, that the space below for a Ø7 mm head/tool and the platform pass-through are clear along the full 25 mm travel of the bolt center. The real tool handle, access blocked by other assembled parts, and strength after fastening need separate checking.

The checks apply to the default 66 mm width and the default 156 mm support height. Passing is not guaranteed at other settings or for other robots. Not included: continuous swept volume of simultaneous multi-joint motion, real screw heads, cables, print strength and long-term creep, fastening friction, and tip-over testing. Keep CAD passes and real-world verification separate.

## References

- [Importing and editing STEP in Onshape](https://www.onshape.com/en/resource-center/tech-tips/import-edit-step-iges-parasolid-stl)
- [Importing Assemblies in Onshape](https://www.onshape.com/en/resource-center/tech-tips/tech-tip-importing-assemblies)
- [Official P1S specifications](https://store.bblcdn.com/63ec128d3b8f4f32b7d60fe4dd112ed3.pdf)

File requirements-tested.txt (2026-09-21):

cadquery==2.8.0
mujoco==3.13.0
numpy==2.3.3
scipy==1.16.3
matplotlib==3.10.8

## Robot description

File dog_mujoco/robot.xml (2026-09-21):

<?xml version='1.0' encoding='utf-8'?>
<mujoco model="mg90s_dog">
  <compiler angle="radian" meshdir="assets" autolimits="true" />
  <option timestep="0.001" integrator="implicitfast" gravity="0 0 -9.80665" iterations="80" />
  <default>
    <joint damping="0.002" armature="0.00002" frictionloss="0.001" />
    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
    <position kp="1.8" kv="0.035" forcerange="-0.06 0.06" />
  </default>
  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
  <worldbody>
    <body name="body" pos="0 0 0.1195837861">
      <freejoint name="floating_base" />
      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
      <inertial mass="0.16085522828" pos="-1.746911734e-18 -0.0001740695674 -0.002806351854" fullinertia="7.964786281e-05 0.0001564696206 0.0001857229865 -2.75928781e-22 -1.389157581e-21 3.865778519e-07" />
      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
      <body name="fl_shoulder" pos="0.054 0.024 0">
        <joint name="fl_1" type="hinge" axis="1 0 0" range="-0.1047197551 0.3141592654" />
        <inertial mass="0.0171559814234" pos="0.001084470576 0.0005996856796 -0.03741114424" fullinertia="4.307659121e-06 3.909437951e-06 1.177529886e-06 -1.827410375e-08 -4.199043289e-07 -9.2045744e-08" />
        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
        <body name="fl_thigh" pos="0 0.016 -0.037">
          <joint name="fl_2" type="hinge" axis="0 1 0" range="-0.837758041 0.3490658504" />
          <inertial mass="0.0174277595713" pos="0.0008068119681 -0.01315870807 -0.04503467837" fullinertia="4.878721752e-06 3.96530564e-06 1.698335013e-06 -1.092244822e-07 -4.01146999e-08 -1.153992655e-06" />
          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
          <body name="fl_shank" pos="0 0 -0.044">
            <joint name="fl_3" type="hinge" axis="0 1 0" range="0.0872664626 1.483529864" />
            <inertial mass="0.00248693251831" pos="2.949931231e-13 0.002922681153 -0.01868466929" fullinertia="7.196081843e-07 7.382120084e-07 3.714277955e-08 9.927656636e-20 1.146331928e-17 1.74278207e-08" />
            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
          </body>
        </body>
      </body>
      <body name="fr_shoulder" pos="0.054 -0.024 0">
        <joint name="fr_1" type="hinge" axis="1 0 0" range="-0.3141592654 0.1047197551" />
        <inertial mass="0.0171559814234" pos="0.001084470576 -0.0005996856796 -0.03741114424" fullinertia="4.307659121e-06 3.909437951e-06 1.177529886e-06 1.827410375e-08 -4.199043289e-07 9.2045744e-08" />
        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
        <body name="fr_thigh" pos="0 -0.016 -0.037">
          <joint name="fr_2" type="hinge" axis="0 1 0" range="-0.837758041 0.3490658504" />
          <inertial mass="0.0174277595713" pos="0.0008068119681 0.01315870807 -0.04503467837" fullinertia="4.878721752e-06 3.96530564e-06 1.698335013e-06 1.092244822e-07 -4.01146999e-08 1.153992655e-06" />
          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
          <body name="fr_shank" pos="0 0 -0.044">
            <joint name="fr_3" type="hinge" axis="0 1 0" range="0.0872664626 1.483529864" />
            <inertial mass="0.00248693251831" pos="2.949931247e-13 -0.002922681153 -0.01868466929" fullinertia="7.196081843e-07 7.382120084e-07 3.714277955e-08 -9.9276541e-20 1.146331968e-17 -1.74278207e-08" />
            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
          </body>
        </body>
      </body>
      <body name="bl_shoulder" pos="-0.054 0.024 0">
        <joint name="bl_1" type="hinge" axis="1 0 0" range="-0.1047197551 0.3141592654" />
        <inertial mass="0.0171559814234" pos="-0.001084470576 0.0005996856796 -0.03741114424" fullinertia="4.307659121e-06 3.909437951e-06 1.177529886e-06 1.827410375e-08 4.199043289e-07 -9.2045744e-08" />
        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
        <body name="bl_thigh" pos="0 0.016 -0.037">
          <joint name="bl_2" type="hinge" axis="0 1 0" range="-0.837758041 0.3490658504" />
          <inertial mass="0.0174277595713" pos="-0.0008068119681 -0.01315870807 -0.04503467837" fullinertia="4.878721752e-06 3.96530564e-06 1.698335013e-06 1.092244822e-07 4.01146999e-08 -1.153992655e-06" />
          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
          <body name="bl_shank" pos="0 0 -0.044">
            <joint name="bl_3" type="hinge" axis="0 1 0" range="0.0872664626 1.483529864" />
            <inertial mass="0.00248693251831" pos="-2.949931247e-13 0.002922681153 -0.01868466929" fullinertia="7.196081843e-07 7.382120084e-07 3.714277955e-08 -9.9276541e-20 -1.146331968e-17 1.74278207e-08" />
            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
          </body>
        </body>
      </body>
      <body name="br_shoulder" pos="-0.054 -0.024 0">
        <joint name="br_1" type="hinge" axis="1 0 0" range="-0.3141592654 0.1047197551" />
        <inertial mass="0.0171559814234" pos="-0.001084470576 -0.0005996856796 -0.03741114424" fullinertia="4.307659121e-06 3.909437951e-06 1.177529886e-06 -1.827410375e-08 4.199043289e-07 9.2045744e-08" />
        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
        <body name="br_thigh" pos="0 -0.016 -0.037">
          <joint name="br_2" type="hinge" axis="0 1 0" range="-0.837758041 0.3490658504" />
          <inertial mass="0.0174277595713" pos="-0.0008068119681 0.01315870807 -0.04503467837" fullinertia="4.878721752e-06 3.96530564e-06 1.698335013e-06 -1.092244822e-07 4.01146999e-08 1.153992655e-06" />
          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
          <body name="br_shank" pos="0 0 -0.044">
            <joint name="br_3" type="hinge" axis="0 1 0" range="0.0872664626 1.483529864" />
            <inertial mass="0.00248693251831" pos="-2.949931247e-13 -0.002922681153 -0.01868466929" fullinertia="7.196081843e-07 7.382120084e-07 3.714277955e-08 9.9276541e-20 -1.146331968e-17 -1.74278207e-08" />
            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
          </body>
        </body>
      </body>
    </body>
  </worldbody>
  <actuator>
    <position name="fl_1" joint="fl_1" ctrlrange="-0.1047197551 0.3141592654" />
    <position name="fl_2" joint="fl_2" ctrlrange="-0.837758041 0.3490658504" />
    <position name="fl_3" joint="fl_3" ctrlrange="0.0872664626 1.483529864" />
    <position name="fr_1" joint="fr_1" ctrlrange="-0.3141592654 0.1047197551" />
    <position name="fr_2" joint="fr_2" ctrlrange="-0.837758041 0.3490658504" />
    <position name="fr_3" joint="fr_3" ctrlrange="0.0872664626 1.483529864" />
    <position name="bl_1" joint="bl_1" ctrlrange="-0.1047197551 0.3141592654" />
    <position name="bl_2" joint="bl_2" ctrlrange="-0.837758041 0.3490658504" />
    <position name="bl_3" joint="bl_3" ctrlrange="0.0872664626 1.483529864" />
    <position name="br_1" joint="br_1" ctrlrange="-0.3141592654 0.1047197551" />
    <position name="br_2" joint="br_2" ctrlrange="-0.837758041 0.3490658504" />
    <position name="br_3" joint="br_3" ctrlrange="0.0872664626 1.483529864" />
  </actuator>
  <sensor>
    <gyro name="imu_gyro" site="imu" />
    <accelerometer name="imu_accel" site="imu" />
    <framequat name="ground_truth_orientation" objtype="site" objname="imu" />
  </sensor>
  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
</mujoco>

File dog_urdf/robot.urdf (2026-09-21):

<?xml version='1.0' encoding='utf-8'?>
<robot name="mg90s_dog">
  <link name="body">
    <inertial>
      <origin xyz="-1.746911734e-18 -0.0001740695674 -0.002806351854" rpy="0 0 0" />
      <mass value="0.16085522828" />
      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
    </inertial>
    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
  </link>
  <link name="fl_shoulder">
    <inertial>
      <origin xyz="0.001084470576 0.0005996856796 -0.03741114424" rpy="0 0 0" />
      <mass value="0.0171559814234" />
      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
    </inertial>
    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
  </link>
  <joint name="fl_1" type="revolute">
    <parent link="body" />
    <child link="fl_shoulder" />
    <origin xyz="0.054 0.024 0" rpy="0 0 0" />
    <axis xyz="1 0 0" />
    <limit lower="-0.10471975511965978" upper="0.3141592653589793" effort="0.06" velocity="4.0" />
    <dynamics damping="0.002" friction="0.001" />
  </joint>
  <link name="fl_thigh">
    <inertial>
      <origin xyz="0.0008068119681 -0.01315870807 -0.04503467837" rpy="0 0 0" />
      <mass value="0.0174277595713" />
      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
    </inertial>
    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
  </link>
  <joint name="fl_2" type="revolute">
    <parent link="fl_shoulder" />
    <child link="fl_thigh" />
    <origin xyz="0 0.016 -0.037" rpy="0 0 0" />
    <axis xyz="0 1 0" />
    <limit lower="-0.8377580409572782" upper="0.3490658503988659" effort="0.06" velocity="4.0" />
    <dynamics damping="0.002" friction="0.001" />
  </joint>
  <link name="fl_shank">
    <inertial>
      <origin xyz="2.949931231e-13 0.002922681153 -0.01868466929" rpy="0 0 0" />
      <mass value="0.00248693251831" />
      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
    </inertial>
    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
  </link>
  <joint name="fl_3" type="revolute">
    <parent link="fl_thigh" />
    <child link="fl_shank" />
    <origin xyz="0 0 -0.044" rpy="0 0 0" />
    <axis xyz="0 1 0" />
    <limit lower="0.08726646259971647" upper="1.4835298641951802" effort="0.06" velocity="4.0" />
    <dynamics damping="0.002" friction="0.001" />
  </joint>
  <link name="fr_shoulder">
    <inertial>
      <origin xyz="0.001084470576 -0.0005996856796 -0.03741114424" rpy="0 0 0" />
      <mass value="0.0171559814234" />
      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
    </inertial>
    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
  </link>
  <joint name="fr_1" type="revolute">
    <parent link="body" />
    <child link="fr_shoulder" />
    <origin xyz="0.054 -0.024 0" rpy="0 0 0" />
    <axis xyz="1 0 0" />
    <limit lower="-0.3141592653589793" upper="0.10471975511965978" effort="0.06" velocity="4.0" />
    <dynamics damping="0.002" friction="0.001" />
  </joint>
  <link name="fr_thigh">
    <inertial>
      <origin xyz="0.0008068119681 0.01315870807 -0.04503467837" rpy="0 0 0" />
      <mass value="0.0174277595713" />
      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
    </inertial>
    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
  </link>
  <joint name="fr_2" type="revolute">
    <parent link="fr_shoulder" />
    <child link="fr_thigh" />
    <origin xyz="0 -0.016 -0.037" rpy="0 0 0" />
    <axis xyz="0 1 0" />
    <limit lower="-0.8377580409572782" upper="0.3490658503988659" effort="0.06" velocity="4.0" />
    <dynamics damping="0.002" friction="0.001" />
  </joint>
  <link name="fr_shank">
    <inertial>
      <origin xyz="2.949931247e-13 -0.002922681153 -0.01868466929" rpy="0 0 0" />
      <mass value="0.00248693251831" />
      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
    </inertial>
    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
  </link>
  <joint name="fr_3" type="revolute">
    <parent link="fr_thigh" />
    <child link="fr_shank" />
    <origin xyz="0 0 -0.044" rpy="0 0 0" />
    <axis xyz="0 1 0" />
    <limit lower="0.08726646259971647" upper="1.4835298641951802" effort="0.06" velocity="4.0" />
    <dynamics damping="0.002" friction="0.001" />
  </joint>
  <link name="bl_shoulder">
    <inertial>
      <origin xyz="-0.001084470576 0.0005996856796 -0.03741114424" rpy="0 0 0" />
      <mass value="0.0171559814234" />
      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
    </inertial>
    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
  </link>
  <joint name="bl_1" type="revolute">
    <parent link="body" />
    <child link="bl_shoulder" />
    <origin xyz="-0.054 0.024 0" rpy="0 0 0" />
    <axis xyz="1 0 0" />
    <limit lower="-0.10471975511965978" upper="0.3141592653589793" effort="0.06" velocity="4.0" />
    <dynamics damping="0.002" friction="0.001" />
  </joint>
  <link name="bl_thigh">
    <inertial>
      <origin xyz="-0.0008068119681 -0.01315870807 -0.04503467837" rpy="0 0 0" />
      <mass value="0.0174277595713" />
      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
    </inertial>
    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
  </link>
  <joint name="bl_2" type="revolute">
    <parent link="bl_shoulder" />
    <child link="bl_thigh" />
    <origin xyz="0 0.016 -0.037" rpy="0 0 0" />
    <axis xyz="0 1 0" />
    <limit lower="-0.8377580409572782" upper="0.3490658503988659" effort="0.06" velocity="4.0" />
    <dynamics damping="0.002" friction="0.001" />
  </joint>
  <link name="bl_shank">
    <inertial>
      <origin xyz="-2.949931247e-13 0.002922681153 -0.01868466929" rpy="0 0 0" />
      <mass value="0.00248693251831" />
      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
    </inertial>
    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
  </link>
  <joint name="bl_3" type="revolute">
    <parent link="bl_thigh" />
    <child link="bl_shank" />
    <origin xyz="0 0 -0.044" rpy="0 0 0" />
    <axis xyz="0 1 0" />
    <limit lower="0.08726646259971647" upper="1.4835298641951802" effort="0.06" velocity="4.0" />
    <dynamics damping="0.002" friction="0.001" />
  </joint>
  <link name="br_shoulder">
    <inertial>
      <origin xyz="-0.001084470576 -0.0005996856796 -0.03741114424" rpy="0 0 0" />
      <mass value="0.0171559814234" />
      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
    </inertial>
    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
  </link>
  <joint name="br_1" type="revolute">
    <parent link="body" />
    <child link="br_shoulder" />
    <origin xyz="-0.054 -0.024 0" rpy="0 0 0" />
    <axis xyz="1 0 0" />
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

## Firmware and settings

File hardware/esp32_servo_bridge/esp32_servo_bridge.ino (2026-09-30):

// ESP32 + PCA9685 servo bridge (minimal firmware for calibration and testing)
//
// The PC (hardware/calibrate.py) sends pulse widths (µs) over USB serial and this passes them
// straight to the PCA9685. All angle conversion and calibration happens on the PC; the firmware stays simple.
//
// Wiring: ESP32 GPIO21 = SDA, GPIO22 = SCL, 3V3 → PCA9685 VCC, common GND.
//         Servo power: a separate 5 V (5 A or more) supply on the PCA9685 V+ terminal. Never power servos from the ESP32's USB.
// Library: install "Adafruit PWM Servo Driver Library" from the Arduino Library Manager.
//
// Serial protocol (115200 baud, one command per line):
//   ?                 → READY
//   P <ch> <us>       → set one channel. us=0 stops the pulse (servo goes limp) → OK
//   M <us0> ... <us11>→ set all 12 channels at once → OK
//   X                 → stop the pulse on every channel → OK
//   invalid command   → ERR <reason>

#include <Wire.h>
#include <Adafruit_PWMServoDriver.h>

constexpr int SDA_PIN = 21;
constexpr int SCL_PIN = 22;
constexpr int N_CH = 12;
constexpr int US_MIN = 500;   // never output a pulse outside this range
constexpr int US_MAX = 2500;
constexpr uint32_t PCA_OSC_HZ = 27000000;  // varies slightly per board; calibration absorbs the error

Adafruit_PWMServoDriver pca(0x40);
char lineBuf[128];
size_t lineLen = 0;

void setUs(int ch, int us) {
  if (us == 0) {
    pca.setPin(ch, 0);  // full-off: no pulse → servo goes limp and can be turned by hand
    return;
  }
  pca.writeMicroseconds(ch, constrain(us, US_MIN, US_MAX));
}

void allOff() {
  for (int ch = 0; ch < 16; ++ch) pca.setPin(ch, 0);
}

bool parseInt(const char *tok, long &out) {
  if (tok == nullptr) return false;
  char *end;
  out = strtol(tok, &end, 10);
  return *end == '\0';
}

void handleLine(char *line) {
  char *cmd = strtok(line, " ");
  if (cmd == nullptr) return;

  if (strcmp(cmd, "?") == 0) {
    Serial.println("READY");
  } else if (strcmp(cmd, "X") == 0) {
    allOff();
    Serial.println("OK");
  } else if (strcmp(cmd, "P") == 0) {
    long ch, us;
    if (!parseInt(strtok(nullptr, " "), ch) || !parseInt(strtok(nullptr, " "), us) ||
        ch < 0 || ch >= N_CH) {
      Serial.println("ERR usage: P <ch 0-11> <us>");
      return;
    }
    setUs((int)ch, (int)us);
    Serial.println("OK");
  } else if (strcmp(cmd, "M") == 0) {
    long us[N_CH];
    for (int i = 0; i < N_CH; ++i) {
      if (!parseInt(strtok(nullptr, " "), us[i])) {
        Serial.println("ERR usage: M <12 values>");
        return;
      }
    }
    for (int i = 0; i < N_CH; ++i) setUs(i, (int)us[i]);
    Serial.println("OK");
  } else {
    Serial.println("ERR unknown command");
  }
}

void setup() {
  Serial.begin(115200);
  Wire.begin(SDA_PIN, SCL_PIN);
  pca.begin();
  pca.setOscillatorFrequency(PCA_OSC_HZ);
  pca.setPWMFreq(50);
  allOff();  // no servo moves right after power-up
  Serial.println("READY");
}

void loop() {
  while (Serial.available()) {
    char c = (char)Serial.read();
    if (c == '\r') continue;
    if (c == '\n') {
      lineBuf[lineLen] = '\0';
      handleLine(lineBuf);
      lineLen = 0;
    } else if (lineLen < sizeof(lineBuf) - 1) {
      lineBuf[lineLen++] = c;
    }
  }
}

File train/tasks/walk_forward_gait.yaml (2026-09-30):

# Stage 2 task (gait version): walk forward + natural gait
# A new version for comparison with walk_forward.yaml, which stays unchanged.
# Only the feet_air_time / gait_symmetry rewards are added. Requires
# scene_gait.xml with foot contact sensors (via env_gait.py / vec_env_gait.py).

task: walk_forward_gait

episode_length_s: 8.0

target_height: 0.1196
height_scale: 0.04

target_vx: 0.08              # a bit higher than walk_forward.yaml (0.05); too slow and
                              # the robot reaches it by shuffling without real steps
velocity_scale: 0.05

fall_height: 0.05
fall_upright: 0.6

reward_weights:
  upright: 1.0
  height: 0.5
  velocity_track: 1.0
  lateral_penalty: 0.3
  yaw_penalty: 0.2
  action_rate_penalty: 0.01
  torque_penalty: 0.001
  alive: 0.3
  feet_air_time: 8.0          # reward air time when a lifted foot lands
  gait_symmetry: 0.3          # encourage a trot: diagonal leg pairs move together

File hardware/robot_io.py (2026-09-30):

"""Shared I/O module for the real robot.

- Joint specs (range, standing pose): onshape/onshape_mates.csv (same values as dog_mujoco/robot.xml)
- Calibration: hardware_calibration.json (starts from the template if missing)
- Sim joint angle (rad) → PCA9685 pulse (µs) conversion
- ESP32 serial link (pairs with the hardware/esp32_servo_bridge firmware)

Conversion (policy output q is the same sim-frame angle as data.ctrl in train/env.py):
    us = center_us + direction * us_per_rad * (q - zero_rad),  clamped to [min_us, max_us]
"""
from __future__ import annotations

import copy
import csv
import json
import math
import time
from dataclasses import dataclass
from pathlib import Path

ROOT = Path(__file__).resolve().parent.parent
TEMPLATE_PATH = ROOT / "hardware_calibration.template.json"
CALIB_PATH = ROOT / "hardware_calibration.json"
MATES_PATH = ROOT / "onshape" / "onshape_mates.csv"

# PCA9685 channel order = robot.xml actuator order = policy output order
JOINT_ORDER = [f"{leg}_{i}" for leg in ("fl", "fr", "bl", "br") for i in (1, 2, 3)]
US_ABS_MIN, US_ABS_MAX = 500, 2500  # same absolute safety range as the firmware
REQUIRED_FIELDS = ("zero_rad", "direction", "center_us", "us_per_rad", "min_us", "max_us")


@dataclass
class JointSpec:
    name: str
    min_rad: float
    max_rad: float
    stand_rad: float


def load_joint_specs() -> dict[str, JointSpec]:
    specs = {}
    with open(MATES_PATH, encoding="utf-8-sig", newline="") as f:
        for row in csv.DictReader(f):
            name = row["mate_name"].removeprefix("dof_")
            specs[name] = JointSpec(
                name=name,
                min_rad=math.radians(float(row["min_deg"])),
                max_rad=math.radians(float(row["max_deg"])),
                stand_rad=math.radians(float(row["standing_deg"])),
            )
    return specs


def load_calibration() -> dict:
    """Load the saved calibration. If there is none, copy the template and fill zero_rad with the standing pose."""
    path = CALIB_PATH if CALIB_PATH.exists() else TEMPLATE_PATH
    with open(path, encoding="utf-8") as f:
        calib = json.load(f)
    specs = load_joint_specs()
    for ch in calib["channels"]:
        if ch["zero_rad"] is None:
            ch["zero_rad"] = specs[ch["joint"]].stand_rad
    return calib


def save_calibration(calib: dict) -> None:
    calib = copy.deepcopy(calib)
    done = all(is_complete(ch) for ch in calib["channels"])
    calib["status"] = "MEASURED" if done else "PARTIAL_DO_NOT_RUN_POLICY"
    with open(CALIB_PATH, "w", encoding="utf-8") as f:
        json.dump(calib, f, indent=2, ensure_ascii=False)


def channel_cfg(calib: dict, joint: str) -> dict:
    return next(ch for ch in calib["channels"] if ch["joint"] == joint)


def is_complete(ch: dict) -> bool:
    return all(ch.get(k) is not None for k in REQUIRED_FIELDS)


def rad_to_us_unclamped(ch: dict, q: float) -> float:
    return ch["center_us"] + ch["direction"] * ch["us_per_rad"] * (q - ch["zero_rad"])


def rad_to_us(ch: dict, q: float) -> int:
    if not is_complete(ch):
        raise ValueError(f"{ch['joint']} is not fully calibrated")
    us = rad_to_us_unclamped(ch, q)
    return int(round(min(max(us, ch["min_us"]), ch["max_us"])))


class ServoLink:
    """Serial link to the ESP32 servo bridge. dry_run=True only prints commands (practice without hardware)."""

    def __init__(self, port: str | None, baud: int = 115200, dry_run: bool = False):
        self.dry_run = dry_run
        self.ser = None
        if dry_run:
            return
        import serial  # pyserial

        self.ser = serial.Serial(port, baud, timeout=0.5)
        time.sleep(2.0)  # opening the port resets the ESP32, so wait for it to boot
        self.ser.reset_input_buffer()
        for _ in range(5):
            self.ser.write(b"?\n")
            if self._readline() == "READY":
                return
        raise RuntimeError(f"No response from the ESP32 on {port}. Check the firmware upload and the port.")

    def _readline(self) -> str:
        return self.ser.readline().decode(errors="replace").strip()

    def _cmd(self, line: str) -> None:
        if self.dry_run:
            print(f"  [dry-run] {line}")
            return
        self.ser.write((line + "\n").encode())
        reply = self._readline()
        if reply != "OK":
            raise RuntimeError(f"ESP32 error: {line!r} → {reply!r}")

    def set_us(self, channel: int, us: int) -> None:
        self._cmd(f"P {channel} {int(us)}")

    def relax(self, channel: int) -> None:
        self._cmd(f"P {channel} 0")

    def set_all_us(self, us: list[int]) -> None:
        self._cmd("M " + " ".join(str(int(u)) for u in us))

    def relax_all(self) -> None:
        self._cmd("X")

    def close(self) -> None:
        try:
            self.relax_all()
        finally:
            if self.ser is not None:
                self.ser.close()

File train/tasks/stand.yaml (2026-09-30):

# Stage 1 task: Stand & Balance
# Goal: hold the target height quietly and efficiently without falling.
# A realistic first goal even for weak MG90S servos (0.06 N·m torque budget).

task: stand

# Episode / physics settings
episode_length_s: 5.0       # max episode length (s)

# Targets used by the rewards
target_height: 0.1196        # from roll_axis_height_mm in design_summary.json (m)
height_scale: 0.03           # tolerance of the height reward (smaller = stricter)

# Fall (termination) criteria
fall_height: 0.05            # fail if the body drops below this height
fall_upright: 0.6            # fail if uprightness (1.0 = fully upright) drops below this

# Weight per reward term (must match the REGISTRY keys in reward_terms.py)
reward_weights:
  upright: 1.0
  height: 1.0
  ang_vel_penalty: 0.05
  action_rate_penalty: 0.01
  torque_penalty: 0.001
  alive: 0.5

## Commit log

2026-09-21 Add MG90S quadruped dog model, CAD, and simulation assets
    [IMU_envelope.stl, PCA9685_envelope.stl, battery_envelope.stl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]
2026-09-22 Add MuJoCo + rsl_rl training pipeline for MG90S quadruped
    - reward_terms.py: reusable reward functions shared by CPU/GPU envs via a
    common SimState container (sim-to-real consistent: observation uses only
    IMU gyro/accel + action history, reward may use privileged sim state)
    - env.py: single-env CPU (mujoco) Gym-style wrapper for dev/visualization
    - vec_env.py: GPU-parallel batched env (mujoco_warp) implementing
    rsl_rl.env.VecEnv for large-scale parallel training
    - tasks/stand.yaml, tasks/walk_forward.yaml: task configs (reward weights
    only — swapping tasks requires no code changes)
    - ppo_config.py, train.py: PPO training entry point (rsl_rl OnPolicyRunner)
    - play.py: loads a traine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
    [stand.yaml]
2026-09-22 Add gait-reward walking variant and command reference doc
    - robot_gait.xml / scene_gait.xml: adds foot-contact touch sensors
    (fl/fr/bl/br_foot_contact), enlarged foot sites for reliable readout.
    Verified matching contact values on both CPU mujoco and GPU mujoco_warp.
    - reward_terms_gait.py: extends reward_terms.REGISTRY (without modifying it)
    with feet_air_time and gait_symmetry rewards, to discourage the "shuffle
    without lifting legs" local optimum the plain walk_forward.yaml converged
    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
    [robot_gait.xml, scene_gait.xml]
2026-09-30 Translate project to English; add calibration stand, servo tools, bench page
    - Translate all Korean comments, docstrings and user-facing strings in
    train/, hardware/ and the ESP32 firmware to English
    - Rename README.ko.md -> README.md and translate it
    - Add calibration_stand/ (CadQuery source, STEP/STL, validation, README)
    - Add hardware/calibrate.py, hardware/robot_io.py and the ESP32 PCA9685
    servo bridge firmware for per-joint servo calibration
    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
    [base.step, base.stl, cap_left.step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]
2026-09-30 Translate gait training files to English
    Translate Korean comments, docstrings and printed messages in the
    gait-reward training variant (env_gait, vec_env_gait, reward_terms_gait,
    train_gait, dashboard_server_gait, walk_forward_gait.yaml).
2026-10-14 Add hardware calibration, motion test and BNO085 IMU stage (course 01-03)
    Course record (course/): one file per stage, new code per stage.
    Stage 01-02 (calibration, motion):
    - calibrate.py updates, measured hardware_calibration.json (+ backups)
    - motion_test.py: keyboard poses, bounce, hop, paw wave, trot
    - calibration tutorial / walkthrough pages, servo bench fix
    Stage 03 (BNO085 IMU):
    - esp32_imu_bridge firmware: servo protocol + IMU (S, I, R commands),
    per-report callback, 100 kHz I2C, watchdog with sh2_close/re-begin,
    RST (GPIO4) hardware reset, INT (GPIO27) gated reads, sh2_devOn wake
    - imu_link.py, imu_test.py (status, live view, axis wizard), hardware_imu.json
    - imu_motion_test.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
2026-10-14 Add real IMU position, obstacle walking and gait clock training
    - dog_mujoco/robot_imu.xml, robot_gait_imu.xml (+ scene_imu.xml, scene_gait_imu.xml):
    imu site moved from z = +26 mm (bridge above the body) to z = -17 mm, where the
    BNO085 is mounted (inside body floor, center). Axes unchanged: hardware_imu.json
    measured raw_to_body = identity.
    - vec_env_imu.py / train_imu.py / play_imu.py: training on the new IMU position with
    gyro/accel noise, per-episode bias and 0-20 ms latency in the observation.
    - scene_obstacle.xml: 8-12 mm bars every 25 cm across the walking direction.
    - env_obstacle.py / vec_env_obstacle.py / train_obstacle.py / play_obstacle.py:
    actions as offsets from the s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
